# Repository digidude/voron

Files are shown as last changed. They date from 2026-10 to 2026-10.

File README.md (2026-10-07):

# Voron 2.4 — Klipper config + notes

Klipper config, calibration prints, and working notes for a Voron 2.4 (250 mm, BTT Octopus, Beacon RevH, Stealthburner + Clockwork 2, Klipper / Mainsail / KlipperScreen).

The goal of the overhaul: first layers that stick, and a failed print that retries in about a minute instead of 5–20.

**Status (2026-10-04):** `config_v2` is checked in a Klipper simulator but **not yet installed on the printer**. The first real run must be supervised.

## What's where

| Path | What it is |
|---|---|
| [`printer_data/config_v2/`](printer_data/config_v2/) | **The new config.** Its [README](printer_data/config_v2/README.md) has the install steps, rollback, and every change with the reason |
| [`printer_data/config/`](printer_data/config/) | The original config as copied from the Pi on 2026-10-03, kept for comparison. `proposed/` holds the first Step 2 drafts (superseded by `config_v2`) |
| [`test_prints/`](test_prints/) | Calibration prints in the order to run them |
| [`docs/notes/`](docs/notes/) | Working notes: the Step 1 review, the Step 2 drafts, a config_v2 summary, and the [Pi v1/v2 setup runbook](docs/notes/2026-10-07-pi-v1-v2-setup-runbook.md) |

Live guides (shared docs, printable, export to PDF / Word / Markdown):

- **Voron 2.4 Config Overhaul — Handoff Guide:** install walkthrough, Mainsail setup, experiment order, results log
- **Orca Slicer from Scratch — Voron 2.4:** presets, start G-code, calibration, sharing presets

Ask Dan for the links (they're private docs, shared per person).

## Seeing what changed

The history is built so each commit is one step:

1. Original Pi config
2. Step 2 drafts (`config/proposed/`)
3. `config_v2` clean rebuild
4. Macro cleanup (renames, hidden helpers)
5. VIEW_VARIABLES + KlipperScreen menu
6. Test prints, notes, this README

Ways to read the diffs:

- **On GitHub:** click **Commits**, then any commit for a side-by-side diff (gear icon → *Split*). Steps 4 and 5 are the readable ones.
- **Compare two points:** `https://github.com/<user>/voron/compare/<commit-a>...<commit-b>`
- **Locally:** `git log --oneline`, then `git show <commit>` or `git diff <a> <b> -- printer_data/config_v2/macros/`
- **Old vs new config:** the folder layout changed completely, so a file-by-file diff isn't useful. Compare by topic, e.g. `config/active_config/system/start_stop.cfg` vs `config_v2/macros/print_start_end.cfg`. In VS Code: select both files → right-click → *Compare Selected*.

## Not in this repo (on purpose)

- `deprecated_config/telegram_config.conf`: it contains a Telegram bot token and API key.
- The 19 timestamped `printer-2024*/2025*.cfg` auto-backups and Mainsail theme images.
- Ellis' first-layer patch and EM-cube STLs (no license to redistribute). Download them from [Ellis' Print Tuning Guide](https://github.com/AndrewEllis93/Print-Tuning-Guide). See `test_prints/README.md`.
- Everything else in this folder (Klipper, Moonraker, Mainsail, etc.). Those are installed software copied from the Pi, not config.

## Licenses

Config files are a personal setup, shared as-is. `test_prints/` includes GPL-3.0 files from Klipper and Voron Design; see `test_prints/README.md` for sources.

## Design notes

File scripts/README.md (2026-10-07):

# scripts/ — run these ON THE PI

Switch the printer between the original config (**v1**) and the rebuilt one (**v2**) with one command. Both live as git branches in `~/printer_data/config`.

| Script | When | What it does |
|---|---|---|
| `setup-config-git.sh` | Once | Backs up the config, makes it a git repo, commits today's config as branch `v1`, installs config_v2 as branch `v2`, leaves the printer on **v1** |
| `switch-config.sh v1\|v2` | Any time the printer is idle | Saves SAVE_CONFIG changes on the current branch, switches, restarts Moonraker + FIRMWARE_RESTART + KlipperScreen, reports whether Klipper is ready |
| `switch-config.sh` | Any time | Shows which config is active |
| `_common.sh` | — | Shared helpers (idle check, restarts) |

## First time

From the Mac:
```bash
scp -r ~/dev/voron/printer_data/config_v2 pi@<printer>:~/config_v2
scp -r ~/dev/voron/scripts               pi@<printer>:~/scripts
```
On the Pi (SSH):
```bash
chmod +x ~/scripts/*.sh
~/scripts/setup-config-git.sh      # printer stays on v1
~/scripts/switch-config.sh v2      # try v2
~/scripts/switch-config.sh v1      # go back any time
```

## Safety built in
- Refuses to run while a print is running or paused.
- `setup` refuses if the config folder is already a git repo, and makes a full copy to `~/printer_data/config_backup_<date>` first.
- If the Pi user isn't `pi`, `setup` fixes v2's `mainsail-config` include path.
- Nothing is deleted: v2's branch moves `active_config/` and `deprecated_config/` into `archive/`; v1 still has them in place.

## Things to know
- **SAVE_CONFIG results stay with their branch.** PID, Beacon model or mesh saved on v2 doesn't show up on v1.
- **First-layer Z offset is in different places:** v1 hard-codes `SET_GCODE_OFFSET Z=0.04` in `active_config/system/start_stop.cfg`; v2 uses `variable_z_hot_offset` in `macros/print_start_end.cfg`.
- **Mainsail macro groups** are stored in Mainsail, not the config. Groups made for v2 names show missing buttons on v1.
- **Orca needs no change.** Both accept `PRINT_START HOTEND=… BED=…`.
- Compare the two: `cd ~/printer_data/config && git diff v1 v2`

## Tested
In a simulated Pi home folder (Moonraker/systemctl stubbed): setup, v1→v2→v1, auto-save of a SAVE_CONFIG change, refusal while printing, unknown branch, re-running setup, non-`pi` username. After setup and after switching back, v1 is byte-identical to the original config; v2 is identical to `config_v2/`. Not yet run on the real Pi.

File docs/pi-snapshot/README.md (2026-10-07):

# Pi snapshot (2026-10-07)

Read-only capture of the printer Pi from `scripts/backup-pi.sh`. Non-secret half only; the config tarball and Moonraker DB export stay local in `backups/` (gitignored).

Note: `klipper.config` is a stale menuconfig (atmega32u4), not the Octopus build.

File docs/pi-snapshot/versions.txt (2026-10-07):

# name  commit  branch  origin
klipper 461c4e3722c3a897fba1c6b3f0780a5315043842 master https://github.com/Klipper3d/klipper.git
moonraker 9e676eba6b02661a4dfa3ec6e7ac3f3504498e6d master https://github.com/Arksine/moonraker.git
mainsail-config ff3869a621db17ce3ef660adbbd3fa321995ac42 master https://github.com/mainsail-crew/mainsail-config.git
KlipperScreen f2eb6919c0fcbcd4bab91ba59a5708415963d2ac master https://github.com/jordanruthe/KlipperScreen.git
crowsnest cf936dabdcf6a3d1eb0138d8eea9044745b40db6 master https://github.com/mainsail-crew/crowsnest.git
sonar 74494cc37e415e7c43e9e497d53fbabc252a5b40 main https://github.com/mainsail-crew/sonar.git
beacon_klipper 3eb0134607664734ccf5cd94cb51840e1c8b27b3 master https://github.com/beacon3d/beacon_klipper.git
mainsail v2.19.0

# Klipper extras that are symlinks or non-stock (e.g. beacon.py)
/home/pi/klipper-led_effect/src/led_effect.py
/home/pi/beacon_klipper/beacon.py

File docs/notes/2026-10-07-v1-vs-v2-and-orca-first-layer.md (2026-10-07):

# Orca first-layer setup + config v1 → v2 differences (2026-10-07)

"v1" = what's on the Pi today (`printer_data/config/` → `active_config/…`).
"v2" = the rebuild in `printer_data/config_v2/` (not installed yet).
Differences below were pulled by flattening both configs (following every `[include]`) and comparing section by section, then reading the macros.

---

## Part A — Orca: first-layer test with PLA

### Why PLA first
- Sticks to PEI at a low bed temp (60 °C), needs no enclosure heat soak, no warping.
- PETG can bond *too* well to smooth PEI and tear the surface. ASA/ABS need a 10+ min soak and a warm chamber — the hardest case. Get the machine right with PLA, then move back to ASA.
- For PLA: **front doors open or top panel off** (a hot chamber softens PLA in the heatbreak and clogs).
- Clean the PEI sheet with dish soap + hot water first, then don't touch the print area.

### Turning on Advanced in Orca 2.4.2
- It's still there, but it's **per panel**: a small **Advanced** switch in the header of the Process settings in the left sidebar (next to the process preset name). The Printer and Filament settings windows each have their own switch.
- If you can't find it: **OrcaSlicer → Preferences → Developer mode** shows every setting everywhere (same effect, permanent).

### Plate layout (`Klipper Square - 01 first layer.3mf`)
Right now the plate has `Klipper_square.stl` (a multi-layer 60 mm square) + one 0.2 mm patch.
1. Delete `Klipper_square` from the plate (it's not a first-layer test and adds time).
2. Keep `First_Layer_Patch-0.2mm` (matches your 0.2 mm first layer). Right-click → **Clone** → 4 more copies.
3. Place them (Object list → Position X/Y), patch centres at:
   - (40, 40) · (210, 40) · (40, 210) · (210, 210) · (125, 125)
   - These stay inside the mesh area (25–225) and clear of the purge line at X=1.
4. Don't use Arrange (A) — it clusters them in the middle.

### Settings to change

| Where | Setting | Now | Change to | Why |
|---|---|---|---|---|
| Plate dropdown (top of plate) | Plate type | High Temp Plate | Match your sheet (Textured PEI or High Temp/smooth PEI) | Orca picks bed temp by plate type |
| Filament: Generic PLA @System | Bed temp, first layer + other layers | 55 °C | **60 °C** | Standard PLA-on-PEI temp |
| Filament | Nozzle temp | 220 / 220 | keep | Fine for generic PLA |
| Process → Speed → Initial layer | First layer speed | 50 mm/s | **30 mm/s** | Slow while diagnosing |
| Process → Speed → Initial layer | First layer infill speed | 105 mm/s | **40 mm/s** | 105 is fast enough to drag lines off |
| Process → Others → Bed adhesion | Brim type | Auto | **No-brim** (for this test only) | A brim on a 1-layer patch hides what you're judging |
| Printer → Motion ability | Emit limits to G-code | On (max accel 20000, speed 300, jerk 12) | **Off** — or set to match printer.cfg (accel 4000, speed 300) | When on, Orca sends `SET_VELOCITY_LIMIT` that overrides printer.cfg's 4000 accel cap |
| Process → Speed → Acceleration | Enable accel_to_decel | On | **Off** | Klipper deprecated ACCEL_TO_DECEL (replaced by minimum_cruise_ratio) |

Leave alone (already right): first layer height 0.2, first-layer line width 0.5, first-layer accel 500, fan off for layer 1, flow ratio 0.98, Orca pressure advance off (Klipper's 0.04 applies), relative E, label objects on, start G-code `PRINT_START HOTEND=… BED=…` (works with both v1 and v2).

### Running it
1. Slice, send, start. Watch the first patch go down.
2. Babystep Z in Mainsail (±0.01–0.02) until lines just merge — no gaps, no ridges.
3. Note the total babystep. On v2 it's added to `variable_z_hot_offset` (now 0.04); on v1 it goes in the hard-coded `SET_GCODE_OFFSET Z=0.04` near the end of `PRINT_START` in `active_config/system/start_stop.cfg`.
4. Corners vs. centre tell you whether it's Z offset (all the same) or mesh/QGL (corners differ).

**Heads-up:** until v2 is installed, every attempt runs v1's full PRINT_START (4 homes + full 81-point mesh, no retry shortcut). That's the 5–20 min. See Part C to get v2 on with an easy way back.

---

## Part B — v1 vs v2, step by step

### 1. PRINT_START sequence (the big one)

| # | v1 (today) | v2 |
|---|---|---|
| 0 | Clear mesh, zero offset | Same + relative extrusion (M83), cancel keep-hot timer, set exhaust policy |
| 1 | **Home first** (G28), bed not heating yet | **Start bed + nozzle (150 °C) heating, then home** while they heat |
| 2 | Nozzle 150, **wait for bed** | Park over bed centre, wait for bed |
| 3 | No soak | **Soak 10 min only if bed ≥ 90 °C** (ASA/ABS). PLA: none. Chamber-temp wait if a chamber thermistor is added |
| 4 | `G32`: G28 → QGL → **full G28 again** | Beacon `CALIBRATE=1` on the **hot** bed → QGL (Beacon's recommended order) |
| 5 | Wipe ×1 → contact Z with **CALIBRATE=1** | Wipe ×2 → contact Z (CALIBRATE=0) — the Z zero that's actually used |
| 6 | **Full bed mesh, 9×9 = 81 pts** (`ADAPTIVE=0`) | **Adaptive mesh** (only where parts are), 15×15 density, Beacon scan |
| 7 | Wipe ×3 → **another contact Z** | — (not needed: Z already set after the wipe) |
| 8 | Move over bucket, wait for print temp | Move over bucket, wait for print temp |
| 9 | Wipe ×2, `SET_GCODE_OFFSET Z=0.04` (hard-coded) | `SET_GCODE_OFFSET Z={z_hot_offset}` (one tunable, 0.04) |
| 10 | `_purge_clean` + `_PURGE_LINE` (absolute-E purge, 15 mm retracts, 11 s pauses) | `NOZZLE_PRIME` → `NOZZLE_CLEAN` → `NOZZLE_PURGE_LINE` (relative-E, 0.5 mm retracts, 1 s pauses) |
| — | Every attempt does all of the above | **Retry mode:** if still homed + QGL'd + bed within 15 °C → skips homing, soak, calibrate and QGL. `FULL=1` forces the full run |
| — | No timing | `PS: <step> @ Ns` lines in the console show where time goes |

Net: v1 = 4 homing passes + 81-point mesh every time. v2 = 1 home + 1 hot calibrate + 1 contact Z first time; retries go straight to wipe → Z → mesh → heat → purge.

### 2. Cancel, end of print, idle

| | v1 | v2 |
|---|---|---|
| Cancel | Mainsail default (turns heaters off) | Parks over bucket, 1 mm retract, **keeps bed hot + nozzle 150 °C for 15 min** (works from Mainsail, KlipperScreen, Orca) |
| PRINT_END | 10 mm retract, park at **fixed Z50** (crashes into parts taller than 50 mm), brush wipe | 2 mm retract, park **≥10 mm above the part**, no wipe at bed level |
| Motors after print | stay on until idle_timeout (but v1's PRINT_START re-homes anyway) | stay on until idle_timeout — and PRINT_START **uses** that to skip homing/QGL |
| idle_timeout | 7200 s (2 h) | 1800 s (30 min) |

### 3. Safety fixes

| Setting | v1 | v2 |
|---|---|---|
| extruder `min_temp` | -200 | 0 (instant unplugged/broken-thermistor detection back on) |
| extruder `min_extrude_temp` | 0 | 170 (cold-extrusion protection back on) |
| heater_bed `min_temp` | -250 | 0 |
| `[verify_heater]` extruder/bed | Klipper defaults (always on, just not written in the file) | same defaults, written out so they're visible |
| extruder `max_extrude_only_distance` | default (50) | 120 (lets load/unload macros work) |

### 4. Fans

| Fan | v1 | v2 |
|---|---|---|
| Exhaust | `heater_fan`: 100% whenever bed ≥ 60 °C — pulls heat out of the chamber during ASA | `fan_generic` + `_EXHAUST` macro: **off for ASA/ABS**, 60% for PLA/PETG, 100% for 5 min after a print |
| Controller (electronics) | on only when **bed** ≥ 45 °C | `[controller_fan]`: on whenever **motors or heaters** are on, 60 s tail |

### 5. Probe, QGL, mesh

| Setting | v1 | v2 |
|---|---|---|
| QGL speed | 400 (silently capped at 300) | 300 |
| Mesh points | 9×9, always full bed | 15×15, adaptive |
| Beacon `contact_max_hotend_temperature` | default | 180 (explicit) |
| Beacon `home_z_hop_speed` | default | 30 |
| G32 | G28 → QGL → **G28 (all axes)** | G28 → QGL → **G28 Z only** |

### 6. Macros

- **Renamed** (hidden helpers get `_`, buttons get prefixes): `status_*` → `_status_*`; `case_lights_*` → `LIGHTS_CASE_*`; `CLEAN_NOZZLE`/`dynamic_clean`/`BUCKET_PURGE`/`_PURGE_LINE`/`_PURGE_CLEAN` etc. (7 macros) → `NOZZLE_CLEAN`, `NOZZLE_PRIME`, `NOZZLE_PURGE_LINE`; `DUMP_VARIABLES`/`GET_VARIABLE` → `_DUMP_…`/`_GET_…`.
- **Removed:** `PRINT_START_temp`, `_CG32`, `_CQGL`, `fast_motion_demo` (disabled), `dads_sandbox` (was never included).
- **New:** `PREHEAT`, `COOLDOWN`, `KEEP_HOT`, `PARK_FRONT`, `LOAD_FILAMENT`, `UNLOAD_FILAMENT`, `M600`, `CAL_PID_EXTRUDER`, `CAL_PID_BED`, `CAL_INPUT_SHAPER`, `CAL_BEACON_HOT`, `CAL_FIRST_LAYER`, `VIEW_VARIABLES`.
- Visible macro buttons: 45 → 29.

### 7. Everything else

| Area | v1 | v2 |
|---|---|---|
| Mainsail macros | local copy `active_config/mainsail.cfg` (never updates) | `[include /home/pi/mainsail-config/mainsail.cfg]` (updates with Mainsail) — check the Pi username |
| New sections | — | `[gcode_arcs]`, `[save_variables]` (needs empty `variables.cfg`), `[resonance_tester]` on Beacon's accelerometer, MCU + Pi temperature readouts |
| moonraker.conf | `enable_object_processing: False` | `True` (Orca's exclude-object works without slicer help); Telegram + LED-effect updaters removed |
| KlipperScreen.conf | settings only | + View Variables menus (old settings kept) |
| File layout | `active_config/system/…`, `user/…`, `community/…` | `hardware/…`, `macros/…`, `experimental/…` |

### 8. Identical in both
`[printer]` limits (300 mm/s, 4000 accel), all pins, motor currents, endstops, Z gearing, extruder rotation_distance 22.1 + PA 0.04, input shaper (ei 65.2 / mzv 41.8), Beacon serial + Y offset, mesh area 25–225, and the whole SAVE_CONFIG block (PIDs, Beacon model, saved mesh).

---

## Part C — Switching between v1 and v2

**Recommendation: git branches in `~/printer_data/config` on the Pi.** One command flips every file (printer.cfg, includes, moonraker.conf, KlipperScreen.conf) at once, and `git diff v1 v2` is the same diff your son already reviews.

### Scripts (in this repo: `scripts/`)
- `setup-config-git.sh` — one time. Backs up, creates branch `v1` (today's config, untouched) and `v2` (config_v2 installed per its README steps 2–5), leaves the printer on v1.
- `switch-config.sh v1|v2` — refuses mid-print, commits any SAVE_CONFIG changes on the current branch, switches, restarts Moonraker + FIRMWARE_RESTART + KlipperScreen, reports whether Klipper is ready.
- Full instructions and test notes: `scripts/README.md`.

### Gotchas
- **SAVE_CONFIG is per branch.** A new PID, Beacon model or mesh saved on v2 stays on v2. If you want it on v1 too, copy the `#*#` block across (or `git checkout v2 -- printer.cfg` and edit).
- **Z offset is in different places:** v1 hard-codes 0.04 in PRINT_START; v2 uses `variable_z_hot_offset`. Tune each separately if you go back and forth.
- **Mainsail macro groups** live in Mainsail's database, not the config. Groups set up for v2 names will show missing buttons on v1. Cosmetic.
- **Orca needs no change** — both versions accept `PRINT_START HOTEND=… BED=…`.
- Later, if you want a button for it: Klipper's `gcode_shell_command` extension can run the script from Mainsail. Not worth it until you're switching often.

**Simpler alternative (no git):** keep two folders, `config_v1/` and `config_v2/`, and swap with `mv` + restart. Works, but it's easy to lose a SAVE_CONFIG change and harder to see what differs.

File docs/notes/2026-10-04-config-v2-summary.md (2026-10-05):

# config_v2 — full replacement config (2026-10-03 / 2026-10-04)

Location: `printer_data/config_v2/` (README.md inside has install, rollback, full change list). Supersedes the earlier drafts in `printer_data/config/proposed/`.

Validation: loaded and run in Klipper batch mode at the Pi's exact Klipper version (v0.13.0-419-g2e5802370) with an STM32F446 dictionary; no config errors or deprecation warnings; all macros executed (print, cancel, retry, PRINT_END, G32, M600/RESUME, utilities). [beacon] was stubbed with [probe] for the simulation; Beacon option names verified against the installed beacon.py (v2.0.0-23). Real heating/probing/timing untested. Note: `klipper/out/klipper.dict` on the Mac is a stale AVR build; build a fresh STM32F446 dict for simulation.

Key decisions:
- Baseline: official Voron 2.4 Octopus layout + Beacon contact docs; not Klippain (last release v4.4.0-beta.1, June 2024).
- Mainsail macros included from /home/pi/mainsail-config/mainsail.cfg (verify Pi username).
- Exhaust fan -> fan_generic + _EXHAUST policy; controller fan -> [controller_fan].
- PRINT_START: retry-aware, hot-bed Beacon CALIBRATE=1 before QGL, contact Z after wipe, adaptive 15x15 mesh, z_hot_offset 0.04 (Beacon suggests ~0.06 start).
- Cancel keeps bed/150C nozzle for 15 min; motors stay on after PRINT_END; idle_timeout 1800. Keep-hot is automatic on Mainsail/KlipperScreen/Orca cancel (via _CLIENT_VARIABLE user_cancel_macro); retry = reprint within 15 min.
- Safety limits fixed (min_temp 0, min_extrude_temp 170).
- resonance_tester uses Beacon accelerometer; RP2040 ADXL kept as disabled file.

## Macro cleanup (2026-10-04)
- Convention: UPPER_CASE = user button; `_` prefix = hidden helper/console tool; prefixes CAL_, LIGHTS_, NOZZLE_, PARK_.
- Hidden: `_status_*` (11), `_set_logo_leds_off`, `_set_nozzle_leds_on/off`, `_DUMP_VARIABLES`, `_GET_VARIABLE`.
- Renamed: LIGHTS_CASE_WHITE/OFF/NIGHT; CAL_PID_EXTRUDER, CAL_PID_BED, CAL_INPUT_SHAPER (was SHAPER_CALIBRATE_ALL), CAL_BEACON_HOT, CAL_FIRST_LAYER; NOZZLE_CLEAN, NOZZLE_PRIME (was BUCKET_PRIME), NOZZLE_PURGE_LINE.
- Kept standard names: PRINT_START/END, G32, M600, LOAD_/UNLOAD_FILAMENT (Mainsail/KlipperScreen buttons), PAUSE/RESUME/CANCEL_PRINT.
- experimental/demo_motion_macros.cfg -> .cfg.disabled (empty experimental glob is OK in Klipper).
- Visible macros 45 -> 28 (29 with VIEW_VARIABLES). Re-simulated: all renamed macros run; old names return Unknown command.
- Mainsail macro groups (Print / Prep / Toolhead / Calibration / Lights / Learn) are a manual UI step — layout in config_v2/README.md.

## View Variables (2026-10-04)
- `VIEW_VARIABLES` (macros/debug.cfg): SHOW=tunables (default; list in `_VIEW_TUNABLES.variable_macros`), SHOW=state (homed/QGL/mesh/temps/offset + predicts RETRY vs FULL PRINT_START with reason), NAME= (-> _DUMP_VARIABLES), PATH= (-> _GET_VARIABLE). Read-only.
- New `config_v2/KlipperScreen.conf`: "View Variables" submenu in both __main and __print (My Settings / Printer State / Open Console); auto-generated block from the old file preserved. Verified with KlipperScreen's own config loader.
- Simulated in Klipper: all modes, cold / after PRINT_START / after cancel / after COOLDOWN.

Open items: chamber thermistor, BeaconPrinterTools thermal expansion calibration, Orca flow ratio (0.926) + brim, first supervised test on the Pi, Pi undervoltage/throttling warnings (power supply).

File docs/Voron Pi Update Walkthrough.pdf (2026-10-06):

# Voron Pi UpdateWalkthrough

Oct 4, 2026 · @Daniel Klaussen

## Whatthis is and why

The Voron's Raspberry Pi needs four updates, done in a fixed order: package sources, operating system, printer software, then the main board's firmware. Nothing here changes the printer's settings ( printer.cfg and friends stay as they are).
Why now:
The Pi's operating system is out of support. It runs Debian 11 "Bullseye", which reached end of life on August 31, 2026. Debian moved its packages to an archive server, so apt upgrade now fails with hundreds of 404 errors.
The main board's firmware is about three years old. The BTT Octopus runs Klipper v0.11.0 firmware, while the Pi now runs Klipper v0.13. Mainsail shows a warning: MCU 'mcu' has deprecated code… Recompiling and flashing is recommended. It still prints, but the gap will eventually become a hard error.
What it touches: the Pi's package list, the Klipper/Moonraker/Mainsail software, and the Octopus firmware. The Beacon probe updates its own firmware and needs nothing by hand.
What it does not do: reinstall the operating system. That's a separate, later job (see the last section).
Risk: low. The config gets backed up first, and the firmware flash goes through the Octopus's built-in bootloader, which the flash never overwrites. A wrong setting means the board won't connect until it's reflashed correctly. It does not brick the board.

## The order, and why it matters

Each step depends on the one before it. Don't skip ahead.
1. Back up the config. Insurance for everything that follows.
2. Fix the package sources. apt can't download anything until it points at Debian's archive server.
3. Upgrade the OS packages, then reboot. Klipper and Moonraker run on top of these libraries (Python, systemd, OpenSSL), so the foundation goes first.

Voron Pi Update Walkthrough

4. Update the printer software in Mainsail's update manager. Order: Moonraker, then Klipper and Beacon together, then everything else. Klipper and the Beacon plugin must end up on matching versions, because the plugin hooks into Klipper's Z homing code, which changed in May 2026.
5. Reflash the Octopus firmware. It has to be built from the Klipper version installed in
step 4. Flash it any earlier and it will be out of date again as soon as Klipper updates.
6. Verify. Restart, check versions, home, level, and read the logs.
If update manager was already run before steps 2 and 3, that's fine. Do steps 2 and 3, then open update manager again and confirm everything shows as up to date before moving to
step 5.

## Before you start

You'll need:
A computer that can SSH into the Pi (user pi ). Replace <printer-ip> below with the Pi's address.
A microSD card, 32 GB or smaller, formatted FAT32, and a way to write to it.
Physical access to the printer. The Octopus's SD slot is inside the electronics bay.
No print running.
Back up the config (step 1). On the Pi:

cd ~
tar czf printer_data-backup-$(date +%F).tgz printer_data/config

Then copy it off the Pi, from your own computer:

scp pi@<printer-ip>:~/printer_data-backup-*.tgz ~/Desktop/

Note the current Klipper version in case you need to roll back:

git -C ~/klipper log -1 --format='%h %cs'

Write it here: ______________________

## Step 2: Point apt at Debian's archive

Save a copy of the current sources file, then look at what's there:

sudo cp /etc/apt/sources.list /etc/apt/sources.list.bak
cat /etc/apt/sources.list
ls /etc/apt/sources.list.d/

Edit the file with sudo nano /etc/apt/sources.list . Replace every Debian line
( deb.debian.org or security.debian.org ) with these two:

deb http://archive.debian.org/debian bullseye main contrib non-free
deb http://archive.debian.org/debian-security bullseye-security main contrib non-free

Delete any bullseye-updates or bullseye-backports line, or put # in front of it. Leave raspi.list in /etc/apt/sources.list.d/ alone. That's the Raspberry Pi repo, and it still works.
Save with Ctrl+O, Enter, then exit with Ctrl+X. Then:

sudo apt update

Expected: no 404 errors. If it says a Release file "is not valid yet" or "has expired", run this instead:

sudo apt -o Acquire::Check-Valid-Until=false update

## Step 3: Upgrade the OS packages and reboot

sudo apt upgrade

Answer Y to continue.
If it asks whether to keep or replace a config file (nginx, sshd), choose keep your currently-installed version. That's the default, so just press Enter.
About 125 packages should install, the same list that failed before (systemd, OpenSSL, Python 3.9, nginx and so on).
When it finishes:

sudo reboot

Wait for the Pi to come back, then confirm Mainsail loads in the browser before going on.

## Step 4: Update the printer software

4a. Check the Klipper folder for local edits first. Klipper's version currently ends in -dirty , which means files in ~/klipper were edited. Update manager may refuse to update a dirty repo.

git -C ~/klipper status --short
git -C ~/klipper diff --stat

Nothing listed: go to 4b.
Files listed, but diff --stat shows 0 insertions, 0 deletions : only file permissions changed. Fix it with git -C ~/klipper config core.fileMode false and check again.
Real line changes: stop. Don't use "Hard Recovery" in Mainsail, because that wipes the changes. Save the git diff output and decide whether those edits matter before continuing.
4b. Run update manager in this order. In Mainsail, go to Machine → Update Manager and click Refresh. Then:
1. System (OS packages). Should now show nothing to do after step 3.
2. moonraker
3. klipper, then beacon right after it. Never leave one updated and the other behind.
4. Everything else: mainsail, mainsail-config, KlipperScreen, crowsnest, led_effect, sonar, moonraker-telegram-bot.
Expected: every row shows as up to date, none as dirty or invalid.
Note: Moonraker 0.11 now rejects a wrong API key instead of falling back to trusted-network access. If the Telegram bot stops responding afterwards, that's the likely cause. It's a nice-to-have, not needed to print.

## Step 5: Reflash the Octopus firmware

The Octopus (STM32F446) talks to the Pi over the Pi's GPIO serial pins ( /dev/ttyAMA0 ), not USB. So the firmware goes on by SD card.
5a. Build the firmware on the Pi:

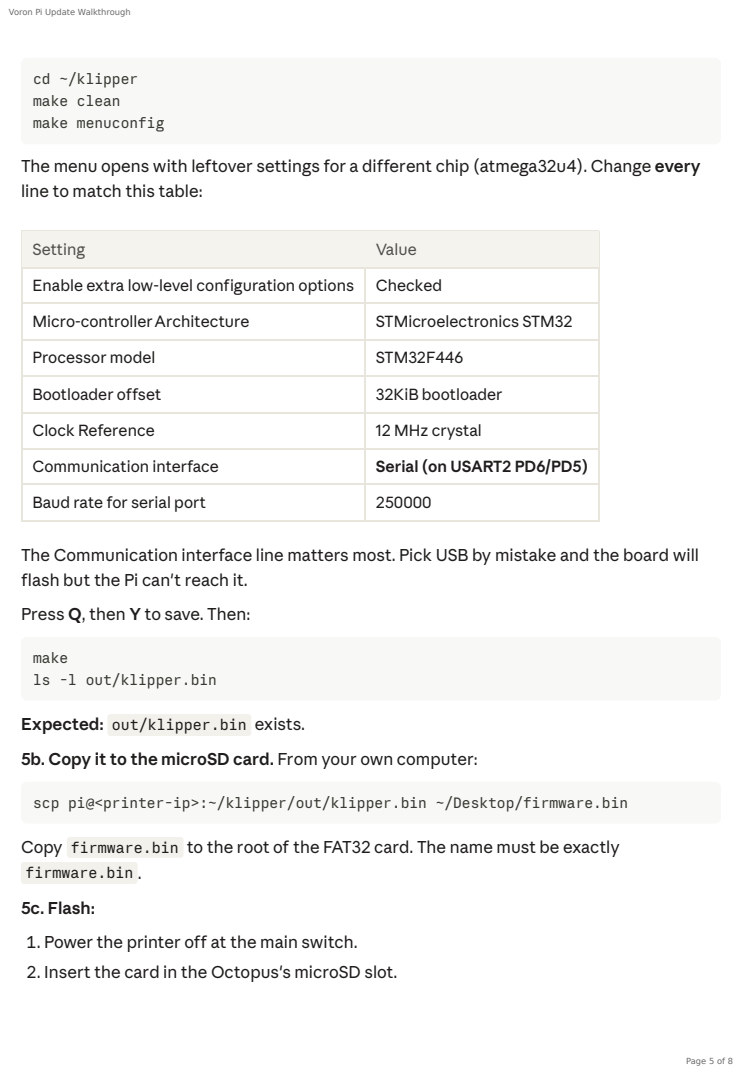
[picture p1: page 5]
cd ~/klipper make clean make menuconfig

The menu opens with leftover settings for a different chip (atmega32u4). Change every
line to match this table:

Setting | Value
Enable extra low-level configuration options | Checked
Micro-controllerArchitecture | STMicroelectronics STM32
Processor model | STM32F446
Bootloader offset | 32KiB bootloader
Clock Reference | 12 MHz crystal
Communication interface | Serial (on USART2 PD6/PD5)
Baud rate for serial port | 250000

The Communication interface line matters most. Pick USB by mistake and the board will
flash but the Pi can't reach it.
Press Q, then Y to save. Then:

make
ls -l out/klipper.bin

Expected: out/klipper.bin exists.
5b. Copy it to the microSD card. From your own computer:

scp pi@<printer-ip>:~/klipper/out/klipper.bin ~/Desktop/firmware.bin

Copy firmware.bin to the root of the FAT32 card. The name must be exactly
firmware.bin .
5c. Flash:
1. Power the printer off at the main switch.
2. Insert the card in the Octopus's microSD slot.

3. Power on and wait about 30 seconds.
4. Power off and remove the card.
5. Check the card on your computer. If the file is now named FIRMWARE.CUR , the flash worked.
6. Power the printer back on.
The Beacon probe updates its own firmware when Klipper starts, so there's nothing to do for it. If the ADXL accelerometer (rp2040) is plugged in and Mainsail shows a version warning for it too, it needs its own build. It isn't needed for printing, so leave it unplugged for now.

## Step 6: Verify

In Mainsail, with the printer powered on:

grep -iE "deprecat|error|mismatch" ~/printer_data/logs/klippy.log | tail -30
grep -iE "deprecat|error|warning" ~/printer_data/logs/moonraker.log | tail
-30

Some old error lines from before the update are normal. Look at the newest ones, at the bottom.

No MCU warning. The deprecated code message is gone.
Versions match. Under Machine → System Loads, mcu shows a v0.13.0 version that matches the Klipper host version, and beacon shows its version.
Home all ( G28 ). All three axes home normally. Watch the first Z home closely, with a hand near the power switch.
Quad gantry level ( QUAD_GANTRY_LEVEL ). Completes without errors.
Heaters. Set the bed to 60 °C and the nozzle to 150 °C. Both reach temperature and hold it.
Logs are clean. On the Pi:

## If something goes wrong

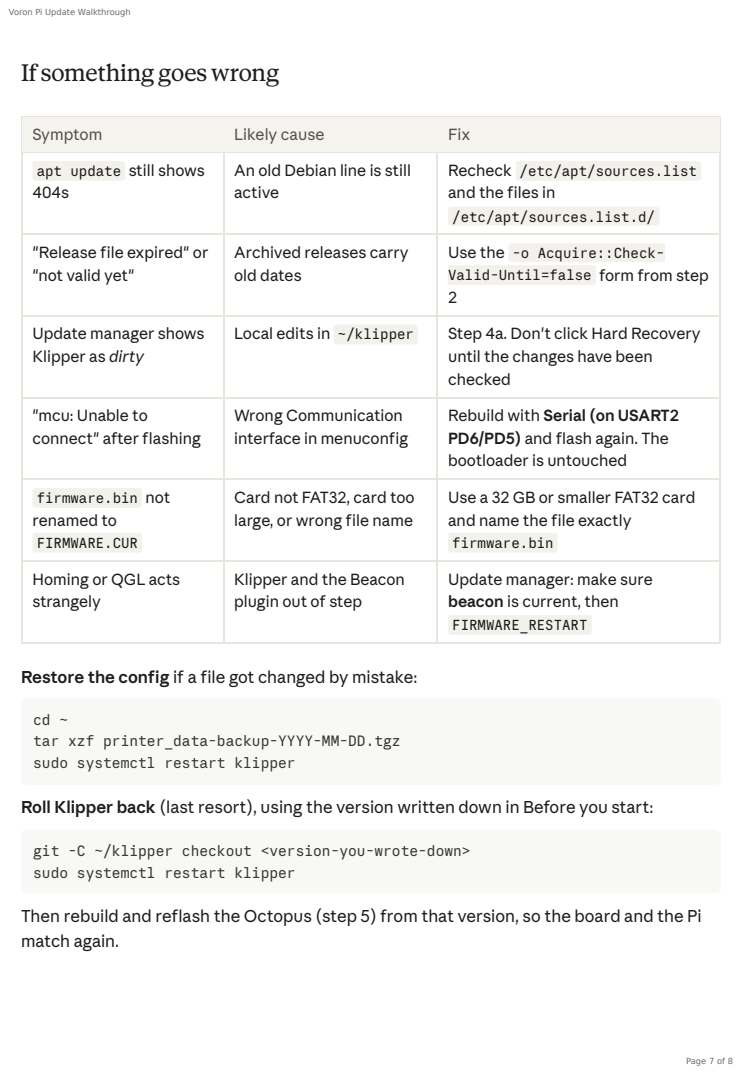
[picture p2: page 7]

Symptom | Likely cause | Fix
apt update still shows 404s | An old Debian line is still active | Recheck /etc/apt/sources.list and the files in /etc/apt/sources.list.d/

"Release file expired" or "not valid yet" | Archived releases carry old dates | Use the -o Acquire::Check-Valid-Until=false form from step 2

Update manager shows Klipper as dirty | Local edits in ~/klipper | Step 4a. Don't click Hard Recovery until the changes have been checked

"mcu: Unable to connect" after flashing | Wrong Communication interface in menuconfig | Rebuild with Serial (on USART2 PD6/PD5) and flash again. The bootloader is untouched

firmware.bin not renamed to FIRMWARE.CUR | Card not FAT32, card too large, or wrong file name | Use a 32 GB or smaller FAT32 card and name the file exactly firmware.bin

Homing or QGL acts strangely | Klipper and the Beacon plugin out of step | Update manager: make sure beacon is current, then FIRMWARE_RESTART

Restore the config if a file got changed by mistake:

tar xzf printer_data-backup-YYYY-MM-DD.tgz
sudo systemctl restart klipper

Roll Klipper back (last resort), using the version written down in Before you start:

git -C ~/klipper checkout <version-you-wrote-down>

Then rebuild and reflash the Octopus (step 5) from that version, so the board and the Pi
match again.

## Later: a fresh operating system

These steps get apt working again, but Bullseye won't receive any more security fixes. That's acceptable for a printer on a home network. Don't expose Mainsail to the internet (no port forwarding).
The proper fix is to reflash the Pi's SD card with current Raspberry Pi OS Lite (Bookworm or Trixie). Then reinstall Klipper, Moonraker, Mainsail, KlipperScreen and Beacon with KIAUH, and copy printer_data/config back in. Plan it after the first-layer work is settled, so the OS and the printer config don't change at the same time.

## Sign-off

Approved to proceed: ______________________ Date: __________ Done by: ______________________ Date: __________

Step 1: Config backed up and copied off the Pi
Step 2: apt sources point at archive.debian.org; apt update runs clean
Step 3: OS packages upgraded; Pi rebooted
Step 4: Update manager all current (Moonraker → Klipper + Beacon → the rest)
Step 5: Octopus flashed; FIRMWARE.CUR on the card
Step 6: No MCU warning; homing, QGL and heaters OK; logs clean

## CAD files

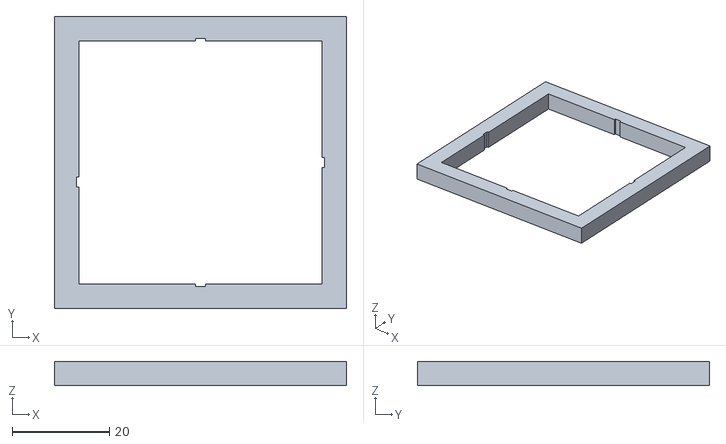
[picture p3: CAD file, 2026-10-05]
test_prints/01_first_layer/Klipper_square.stl
60.0 x 60.0 x 5.00

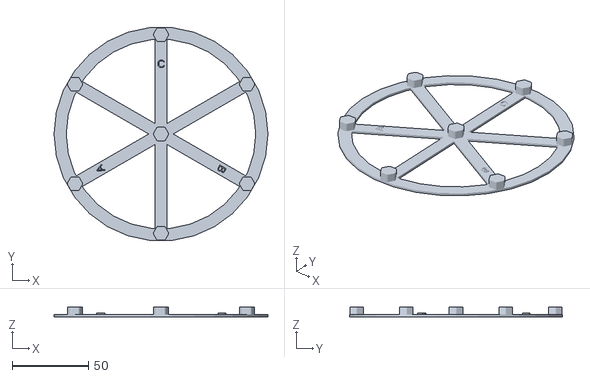
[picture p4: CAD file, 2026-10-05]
test_prints/02_size/calibrate_size.stl
140.0 x 139.2 x 6.50

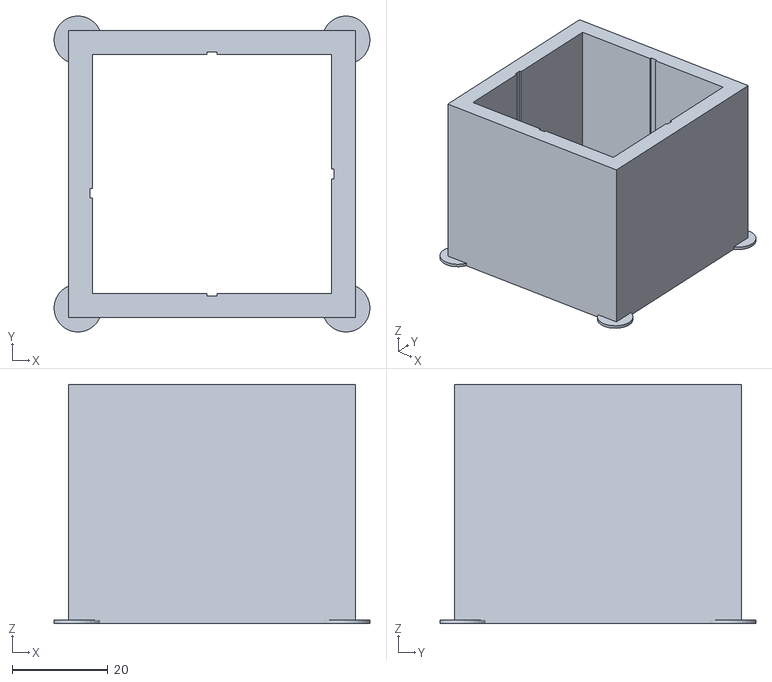
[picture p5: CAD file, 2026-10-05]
test_prints/05_pressure_advance/square_tower.stl
66.0 x 65.9 x 50.0

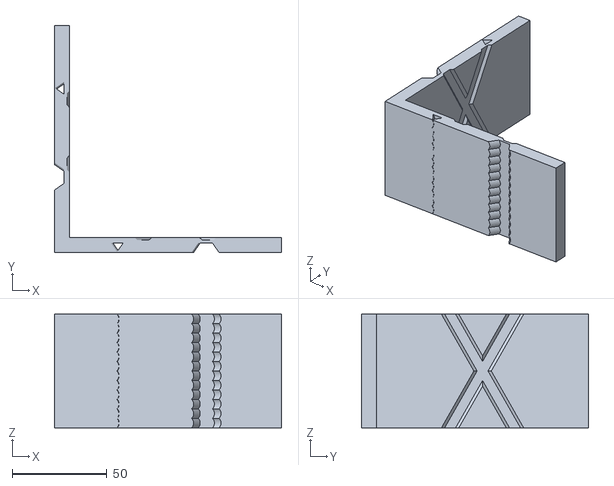
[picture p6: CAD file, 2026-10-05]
test_prints/06_input_shaper_check/ringing_tower.stl
120.0 x 120.0 x 60.0

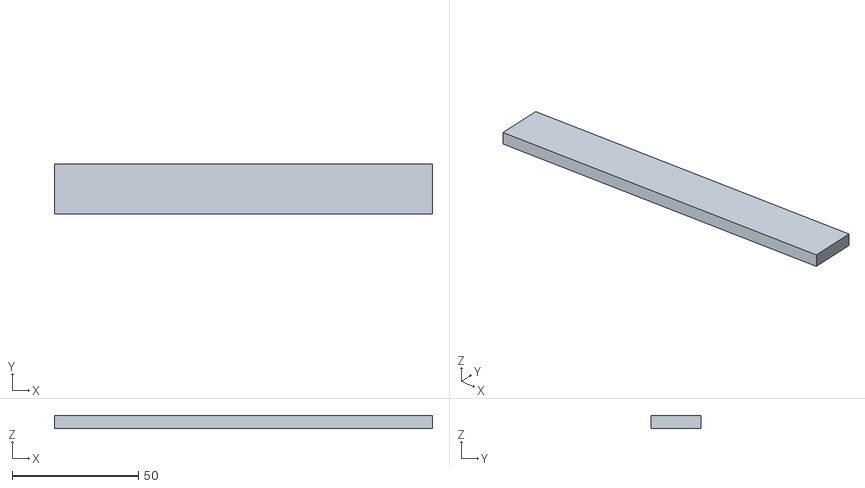
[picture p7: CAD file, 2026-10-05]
test_prints/09_abs_warp_test/Warp_Bar_150x20x5.stl
150.0 x 20.0 x 5.00

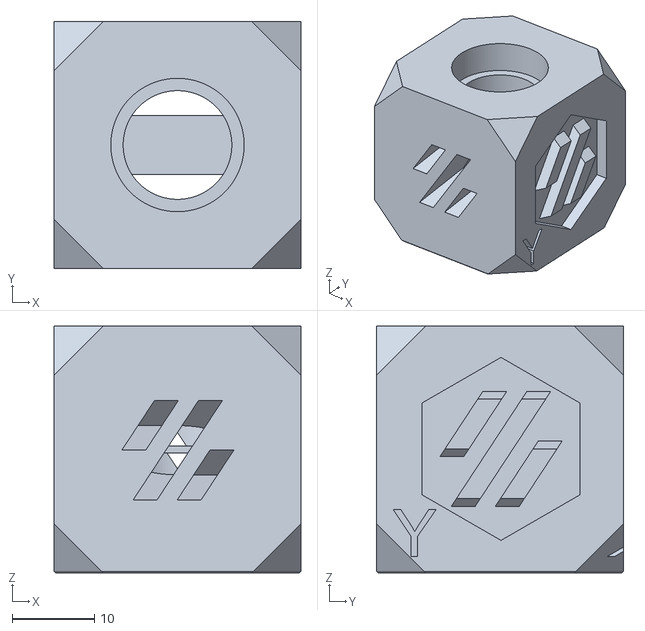
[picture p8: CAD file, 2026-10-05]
test_prints/10_overall_voron_cube/Voron_Design_Cube_v7.stl
30.0 x 30.0 x 30.0

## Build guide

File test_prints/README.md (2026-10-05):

# Voron 2.4 test prints

Run these in folder order: each step assumes the earlier ones are dialed in. Change one thing per print and write down the value (results log in the Handoff Guide).

Steps with no folder (temperature, retraction, max speed, tolerance) are generated inside Orca: **Calibration** menu. No file needed.

| # | Folder / where | File(s) | What it tells you | How to read it |
|---|---|---|---|---|
| 01 | `01_first_layer/` | `First_Layer_Patch-0.2mm.stl` (match your first-layer height; 0.24 / 0.25 / 0.3 also included) | Z offset + mesh, everywhere on the bed | Place 5 copies: 4 corners + center. Babystep live until lines just merge, no gaps or ridges. Add the total to `variable_z_hot_offset` |
| 02 | `02_size/` | `calibrate_size.stl` (Klipper) | X/Y accuracy and skew | Measure with calipers; Klipper's `skew_correction` docs explain the math |
| 03 | Orca → Calibration | Temp tower | Best nozzle temp | Pick the cleanest section |
| 04 | `04_flow_em_cubes/` | `labeled_0.900-1.050/EM_Cube-*.stl` (or the unlabeled one) | Flow ratio (extrusion multiplier) | Ellis' method: print several, pick the smoothest top surface without overfill. Labeled cubes have the value embossed. Your ASA is at 0.926 now; expect 0.95–1.0 |
| 05 | `05_pressure_advance/` | `square_tower.stl` (Klipper) — or Orca's PA pattern | Corner sharpness | Klipper docs: "Pressure advance" tuning. Orca's pattern test is quicker |
| 06 | `06_input_shaper_check/` | `ringing_tower.stl` (Klipper) | Ghosting after `CAL_INPUT_SHAPER` | Ripples next to the notches should be gone |
| 07 | Orca → Calibration | Retraction test | Stringing | Shortest retraction with no strings |
| 08 | Orca → Calibration | Max volumetric speed | Hotend melt limit | Note where the walls start to fail; use ~80% of it |
| 09 | `09_abs_warp_test/` | `Warp_Bar_150x20x5.stl` | ABS/ASA corner lifting | Print along X, 3 walls, 15% infill, no brim first. Lay it on glass: any rocking = warp. Repeat with brim / after chamber thermistor |
| 10 | `10_overall_voron_cube/` | `Voron_Design_Cube_v7.stl` | Overhangs, bridges, text, dimensions | Voron's own all-in-one check. 30 mm cube |
| 11 | Voron GitHub | A real Voron part in ASA (e.g. a spare Stealthburner part) | Final exam | Fits + no warp = done |

**Git note:** Ellis' first-layer patches and EM cubes (`01_first_layer/First_Layer_Patch-*.stl`, everything in `04_flow_em_cubes/`) aren't in the git repo because they have no redistribution license. Download them from his repo (link below) into those folders.

## Sources

- First-layer patches and EM cubes: Ellis' Print Tuning Guide — github.com/AndrewEllis93/Print-Tuning-Guide (`test_prints/`). Guide: ellis3dp.com
- Voron Design Cube v7: github.com/VoronDesign/Voron-2 (`STLs/Test_Prints/`), GPL-3.0 (license in that folder)
- `calibrate_size`, `square_tower`, `ringing_tower`: Klipper (`klipper/docs/prints/`), GPL-3.0
- Warp bar: simple 150 × 20 × 5 mm box generated for this project

Downloaded 2026-10-04.

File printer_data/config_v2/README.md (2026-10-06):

# Voron 2.4 — config_v2

This is a clean rebuild of the Klipper config. The layout follows the official Voron 2.4 / BTT Octopus reference config, and the probing sequence follows Beacon's documentation. All machine-specific values are carried over from your old config. Drafted 2026-10-03.

## Related

- **Handoff Guide** (overview, decisions, and the results log for test prints): https://claude.ai/artifact/BYiP8vtwQ9XhrJBHuGidYb
- **Orca Slicer from Scratch** (slicer setup to pair with this config): https://claude.ai/artifact/4QghdcxjAcYA2dbD4WtgKx
- **Test prints**: `voron/test_prints/README.md` on the Mac copy (`../../test_prints/` from here). 10 calibration steps in order, STLs included. These stay on the Mac; they don't get copied to the Pi.
- **History:** `config/proposed/` held the first Step 2 drafts (PRINT_START, keep-hot, exhaust). All of that is folded into this folder; `proposed/` is kept only for reference. `config/deprecated_config/` and `config/active_config/` are the original files from the Pi; see Install step 2.

## How it was checked

- **Real Klipper, simulated printer.** The config was loaded by the same Klipper version as your Pi (v0.13.0-419) in batch mode, using an STM32F446 build of the firmware. Klipper accepted every section with no errors or deprecation warnings. Every macro ran to completion, including a simulated print, a cancel, a retry, PRINT_END, G32, M600/RESUME and the utility macros.
- **Beacon, by hand instead.** The `[beacon]` section can't be loaded without the physical Beacon attached, so the simulation used a stand-in probe. Every Beacon option name was checked against your installed `beacon.py` instead.
- **Not tested:** real temperatures, real probing and timings. The first real run is still a supervised test.

## File layout

```
printer.cfg                 includes + [mcu] [printer] input shaper, idle timeout, SAVE_CONFIG block
hardware/
  motors.cfg                X/Y/Z steppers + TMC2209 drivers
  extruder.cfg              Clockwork 2 + hotend heater
  bed.cfg                   bed heater
  beacon.cfg                Beacon, QGL, bed mesh, resonance tester
  fans.cfg                  all fans + _EXHAUST policy
  leds.cfg                  case lights + Stealthburner LEDs + hidden _status_ macros
  sensors.cfg               Octopus/Pi temps + chamber thermistor template
macros/
  print_start_end.cfg       PRINT_START (retry-aware) / PRINT_END
  cancel_keep_hot.cfg       cancel = park + keep warm 15 min
  nozzle_clean.cfg          NOZZLE_CLEAN, NOZZLE_PRIME, NOZZLE_PURGE_LINE
  utility.cfg               G32, PARK_*, PREHEAT, COOLDOWN, LOAD/UNLOAD, M600
  calibration.cfg           CAL_PID_*, CAL_INPUT_SHAPER, CAL_BEACON_HOT, CAL_FIRST_LAYER
  debug.cfg                 VIEW_VARIABLES (+ _DUMP_VARIABLES, _GET_VARIABLE)
experimental/               auto-included playground (*.cfg)
moonraker.conf              cleaned up
```

## Install (on the Pi)

1. **Back up the current config.**
   `cp -r ~/printer_data/config ~/printer_data/config_backup_$(date +%F)`
2. **Archive the clutter.** Move the 25 `printer-2024*.cfg` / `printer-2025*.cfg` backups, `active_config/` and `deprecated_config/` into a folder named `archive/`. Klipper ignores any file that nothing includes, so this is only for tidiness.
3. **Copy in the new files.** Copy everything from `config_v2/` into `~/printer_data/config/`: `printer.cfg`, `hardware/`, `macros/`, `experimental/` and `moonraker.conf`. Also copy the new `KlipperScreen.conf` (adds the View Variables menu; your existing settings are preserved at the bottom). Keep your existing `crowsnest.conf` and `sonar.conf`; they're unchanged.
4. **Create the save-variables file.** Klipper won't start without it: `touch ~/printer_data/config/variables.cfg`
5. **Check the Pi username.** The first include in `printer.cfg` assumes it's `pi`: `/home/pi/mainsail-config/mainsail.cfg`. If it isn't, fix that path.
6. **Restart.** Restart Moonraker, then run `FIRMWARE_RESTART` from Mainsail.
7. **First test, supervised.** Home, run `G32`, then a small PLA print (dial in with PLA first). Watch the `PS:` lines in the console.

**Rollback:** copy the backup folder back and run `FIRMWARE_RESTART`.

## What changed, and why

### Fixes

| Where | Change | Why |
|---|---|---|
| extruder.cfg | `min_temp` -200 → 0, `min_extrude_temp` 0 → 170 | Restores thermistor-fault and cold-extrusion protection |
| bed.cfg | `min_temp` -250 → 0 | Same |
| fans.cfg | Exhaust: 100%-when-bed-hot → macro controlled. Off for ABS/ASA, 60% for PLA, 5 minutes at 100% after a print | It was pulling heat out of the chamber, a likely cause of corners lifting |
| fans.cfg | Controller fan follows motors and heaters, not the bed | Drivers and Pi had no airflow on cold-bed jobs |
| nozzle_clean.cfg | Purge rewritten for relative extrusion. Retracts cut from 15 mm to 0.5 mm, pauses from 11 s to 1 s | The old purge started the line under-primed; long retracts at print temperature risk heat creep |
| print_start_end.cfg | PRINT_END parks at least 10 mm above the part | The old fixed Z50 would drive the nozzle *into* parts taller than 50 mm |
| print_start_end.cfg | Defaults for BED/HOTEND | Running PRINT_START by hand without values used 0°C |
| printer.cfg | Mainsail macros included from the `mainsail-config` repo | Your copy wasn't getting updates |
| beacon.cfg | QGL speed 400 → 300 | It was being silently capped at max_velocity |

### Speed (faster attempts and retries)

- **PRINT_START** heats the bed and nozzle while homing. It homes Z with contact once, plus one calibration on the hot bed, instead of 4–6 homes. The mesh is adaptive (only where parts are).
- **Retry mode.** If the printer is still homed, levelled and the bed is within 15°C of target, PRINT_START skips homing, QGL and the soak. Add `FULL=1` to force everything.
- **Keep warm on cancel.** A cancel parks over the bucket, retracts 1 mm, and keeps the bed at print temperature and the nozzle at 150°C for 15 minutes.
- **Motors stay on after PRINT_END,** so the next print can skip homing and QGL. `idle_timeout` turns them off after 30 minutes.
- **Time per step.** `PS: <step> @ Ns` lines show where the time goes.
- **G32** re-homes only Z after QGL.

### Quality

- **Heat soak:** 10 minutes automatically for beds at 90°C and above. A chamber-temperature wait takes over if you add a chamber thermistor.
- **Beacon calibration on the hot bed** before QGL, as Beacon's docs recommend.
- **Nozzle expansion offset:** `z_hot_offset` (default 0.04; Beacon suggests about 0.06 as a start) is a single setting to tune.
- **Mesh:** 15×15 points (scanning, so almost no extra time). `zero_reference_position` matches the Beacon home spot.

### New nice-to-haves (all optional)

- **Printer config:** `[gcode_arcs]` (for Orca arc fitting) and `[save_variables]` (persistent macro values).
- **Temperature readouts:** Octopus MCU and Pi CPU temperatures in Mainsail.
- **Chamber thermistor:** template included. Recommended ~$2 upgrade.
- **Input shaper:** `[resonance_tester]` uses Beacon's built-in accelerometer. Your old RP2040/ADXL board is kept as `experimental/adxl_rp2040.cfg.disabled`.
- **Utility macros:** `PREHEAT`, `COOLDOWN`, `KEEP_HOT`, `PARK_FRONT`, `LOAD_FILAMENT`, `UNLOAD_FILAMENT`, `M600`.
- **Calibration macros:** `CAL_PID_EXTRUDER`, `CAL_PID_BED`, `CAL_INPUT_SHAPER`, `CAL_BEACON_HOT`, `CAL_FIRST_LAYER`.
- **Case lights:** the macros are one-line `SET_LED` calls now.
- **moonraker.conf:**
  - Object processing on.
  - Beacon updater left on `dev` (Beacon's official setting; its last tagged release is from 2024).
  - Removed the unused Telegram and LED-effect updater entries (notes inside if you want them back).

### Removed

- `PRINT_START_temp`, `_CG32`, `_CQGL`, `dads_sandbox` (it was never included anyway).
- Seven duplicate purge/clean macros, now three.
- The `klipperScreen.cfg` include. It only held KlipperScreen's own settings, which live in `KlipperScreen.conf`.

### Carried over unchanged (machine-specific)

- **Wiring and Beacon:** all pins, the Beacon serial number, the Beacon Y offset of 25, and the MCU on `/dev/ttyAMA0`.
- **Motion:** motor currents, endstop positions, axis limits and Z gear ratio.
- **Extruder:** `rotation_distance` 22.1 with 50:10 gearing, and pressure advance 0.04.
- **Tuning results:** input shaper (ei 65.2 / mzv 41.8), and the entire SAVE_CONFIG block (PID values, Beacon model, saved mesh).
- **Peripherals:** brush, bucket and purge positions, fan pins, LED colours.

## Macro cleanup (2026-10-04)

Goal: a tidy Mainsail Macros panel. Backup of the pre-cleanup files: `printer_data/config_v2.bak-2026-10-04-pre-macro-cleanup/`.

**Naming convention** (also documented at the top of the macro includes in `printer.cfg`):

- `UPPER_CASE` = a command you run by hand; shows as a button.
- `_anything` = internal helper or console tool; Mainsail hides it.
- Prefixes so related buttons sort together: `CAL_*`, `LIGHTS_*`, `NOZZLE_*`, `PARK_*`.
- Left alone on purpose because other tools look for these names: `PRINT_START`/`PRINT_END` (Orca), `G32`, `M600`, `LOAD_FILAMENT`/`UNLOAD_FILAMENT` (Mainsail and KlipperScreen load/unload buttons), `PAUSE`/`RESUME`/`CANCEL_PRINT` (Mainsail).

**Renames**

| Old | New | Why |
|---|---|---|
| `status_*` (11 macros) | `_status_*` | Internal LED helpers; hidden |
| `set_logo_leds_off`, `set_nozzle_leds_on/off` | `_set_...` | Internal LED helpers; hidden |
| `DUMP_VARIABLES`, `GET_VARIABLE` | `_DUMP_VARIABLES`, `_GET_VARIABLE` | Console tools; hidden but still autocomplete in the console |
| `CASE_LIGHTS_WHITE/OFF/NIGHT` | `LIGHTS_CASE_WHITE/OFF/NIGHT` | Prefix grouping |
| `PID_EXTRUDER`, `PID_BED` | `CAL_PID_EXTRUDER`, `CAL_PID_BED` | Prefix grouping |
| `SHAPER_CALIBRATE_ALL` | `CAL_INPUT_SHAPER` | Prefix grouping |
| `BEACON_CALIBRATE_HOT` | `CAL_BEACON_HOT` | Prefix grouping |
| `FIRST_LAYER_CHECK` | `CAL_FIRST_LAYER` | Prefix grouping |
| `CLEAN_NOZZLE`, `BUCKET_PRIME`, `PURGE_LINE` | `NOZZLE_CLEAN`, `NOZZLE_PRIME`, `NOZZLE_PURGE_LINE` | Prefix grouping |
| `fast_motion_demo` | (disabled) | `experimental/demo_motion_macros.cfg` renamed to `.cfg.disabled` |

All internal calls were updated. Every visible macro has a `description:`. Re-tested in the Klipper simulator (same Klipper version, STM32F446 dictionary, Beacon stubbed out because it needs its own MCU): G32, PRINT_START (full and retry), PRINT_END, CANCEL_PRINT + keep-hot, every renamed macro, and the debug tools all ran with no unknown-command or template errors. The old names correctly come back as "Unknown command".

**Result:** 28 visible macros (22 of ours + 6 from Mainsail), down from 45 (29 with VIEW_VARIABLES, added later). The groups below show only the ones that make sense for what the printer is doing.

### Mainsail macro groups (do this in the Mainsail UI)

Mainsail stores groups in its own database, not in the Klipper config, so this step is manual. Go to **Settings → Macros**, switch **Management** to **Expert**, then add these groups. In Expert mode, a macro that isn't in any group doesn't appear on the dashboard, which is how `PRINT_START`, `PRINT_END` and `SET_PRINT_STATS_INFO` stay off it (Orca calls those).

| Group | Show when | Macros |
|---|---|---|
| **Print** | printing, paused | PAUSE, RESUME, CANCEL_PRINT, M600, SET_PAUSE_NEXT_LAYER, SET_PAUSE_AT_LAYER |
| **Prep** | standby | PREHEAT, COOLDOWN, G32, KEEP_HOT, LOAD_FILAMENT, UNLOAD_FILAMENT |
| **Toolhead** | standby, paused | PARK_FRONT, PARK_REAR, NOZZLE_CLEAN, NOZZLE_PRIME, NOZZLE_PURGE_LINE |
| **Calibration** | standby (collapsed) | CAL_FIRST_LAYER, CAL_BEACON_HOT, CAL_PID_EXTRUDER, CAL_PID_BED, CAL_INPUT_SHAPER |
| **Lights** | always | LIGHTS_CASE_WHITE, LIGHTS_CASE_NIGHT, LIGHTS_CASE_OFF |
| **Learn** | always | VIEW_VARIABLES |

Tip: color the Print group red (PAUSE and CANCEL should be easy to find) and Calibration a muted color.

**If you use these anywhere else, update them:** KlipperScreen custom menus, Mainsail console history, or Orca G-code that called `CLEAN_NOZZLE`/`PURGE_LINE` directly. Orca's standard start line (`PRINT_START ...`) is unchanged.

## View Variables (2026-10-04)

One read-only button for "what is the printer thinking?" Safe to press mid-print. Output goes to the console. Backup of the files before this change: `printer_data/config_v2.bak-2026-10-04-pre-view-variables/`.

| Command | Shows |
|---|---|
| `VIEW_VARIABLES` or `SHOW=tunables` | Your tunable settings: PRINT_START, keep-hot, brush/bucket positions, exhaust |
| `VIEW_VARIABLES SHOW=state` | Homed, QGL, mesh, position, Z offset, temps, and whether the next PRINT_START takes the RETRY path (with the reason if not) |
| `VIEW_VARIABLES NAME=<text>` | Free search over everything (uses `_DUMP_VARIABLES`) |
| `VIEW_VARIABLES PATH=<a.b>` | One exact value (uses `_GET_VARIABLE`) |

- **Mainsail:** click the arrow on the VIEW_VARIABLES button to fill in SHOW / NAME / PATH. It's in the **Learn** group above.
- **KlipperScreen:** a **View Variables** menu on the main screen and in the in-print menu, with My Settings, Printer State and Open Console buttons. Defined in `KlipperScreen.conf`.
- To add another macro to the tunables list, edit `variable_macros` in `_VIEW_TUNABLES` (`macros/debug.cfg`).

Tested in the Klipper simulator (cold start, after PRINT_START, after a cancel, after COOLDOWN, all four modes). `KlipperScreen.conf` was loaded with KlipperScreen's own config parser: no errors, and the menus appear in both menus.

## Orca changes to pair with this (in the slicer, not here)

- **Filament flow ratio:** ASA is currently 0.926. Run Orca's flow calibration; if you don't, try 0.95–1.0 for first-layer adhesion.
- **Brim** on parts with sharp corners for ASA/ABS.
- **Machine start G-code:** no change needed. Optional: add `SOAK=0` when the printer is already heat-soaked.
- **Accel-to-decel:** if Orca's "Klipper: use accel_to_decel" is on, consider turning it off. Klipper replaced `max_accel_to_decel` with `minimum_cruise_ratio` in 2024.

## Suggested next upgrades (not done here)

1. **Chamber thermistor:** see `hardware/sensors.cfg`.
2. **Thermal expansion calibration:** [BeaconPrinterTools](https://github.com/YanceyA/BeaconPrinterTools) measures your nozzle's expansion and sets `z_hot_offset` automatically for each print temperature.
3. **Re-run tuning:** work through `test_prints/README.md` in order (first layer → size → temp → flow → pressure advance → input shaper check → ABS warp). `CAL_INPUT_SHAPER` comes before step 06. Log results in the Handoff Guide.
4. **Mechanical checks:** belt tension (including matched Z belts), bed mounting (one bolt fixed, the others free to slide), and a clean PEI sheet (dish soap and water).

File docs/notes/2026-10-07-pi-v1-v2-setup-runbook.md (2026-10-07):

# Runbook: set up v1/v2 config branches on the Pi

Date: 2026-10-07. Status: **not yet run on the Pi** (as of this note). Everything marked "changes the Pi" needs the owner's OK first.

Result: `~/printer_data/config` becomes a local git repo with branch `v1` (current config, untouched) and `v2` (`config_v2` installed). `switch-config.sh` flips between them. Setup leaves the printer on v1 and restarts nothing.

## Preflight (read-only, checked 2026-10-07)

| Check | Result |
|---|---|
| `git`, `curl`, `python3` on Pi | present |
| `~/mainsail-config/mainsail.cfg` (v2 includes it) | present |
| Printer state | standby |
| Disk | 44 GB free |
| KlipperScreen service | present |
| `~/config_v2`, `~/scripts` | absent: copy first |
| `sudo` | needs a password, so switching must be from an interactive SSH login |

## Steps

1. **Copy from the Mac** (changes the Pi: adds two new folders):
   ```bash
   scp -r ~/dev/voron/printer_data/config_v2 pi@voron.local:~/config_v2
   scp -r ~/dev/voron/scripts               pi@voron.local:~/scripts
   ```
2. **Log in interactively:**
   ```bash
   ssh pi@voron.local
   chmod +x ~/scripts/*.sh
   ```
3. **Run setup** (changes the Pi: backs up and `git init`s the config; printer stays on v1):
   ```bash
   ~/scripts/setup-config-git.sh
   ```
   Backup goes to `~/printer_data/config_backup_<date>`.
4. **Verify nothing changed on v1:**
   ```bash
   cd ~/printer_data/config
   git branch                # v1 (active), v2
   git status --short        # empty
   git diff --stat v1 v2
   ```
5. **Switch to v2** (printer idle; prompts for sudo password; restarts Moonraker, FIRMWARE_RESTART, KlipperScreen):
   ```bash
   ~/scripts/switch-config.sh v2
   ```
6. **Switch back any time:**
   ```bash
   ~/scripts/switch-config.sh v1
   ~/scripts/switch-config.sh        # show active branch
   ```

## After the first switch to v2, check in Mainsail
- Klipper state is ready; Beacon connected
- Heater, fan and temperature readings look sane
- v2 has no SAVE_CONFIG block: redo PID, Beacon model, and bed mesh on v2. They do not carry over from v1.

## Rollback
`switch-config.sh v1`. Fallback: the `config_backup_<date>` folder from step 3.

## Gotchas
- SAVE_CONFIG results stay on the branch that produced them.
- `variables.cfg` is gitignored and shared by both branches.
- The first real run of the switch scripts: earlier tests used stubs only.
- If Moonraker or Klipper doesn't answer after a switch, open Mainsail for the error, then switch back.

## Related
- `scripts/README.md`: script reference
- `scripts/backup-pi.sh`: read-only backup from the Mac (output in gitignored `backups/`)
- `docs/pi-snapshot/`: non-secret snapshot of the Pi's system state (2026-10-07)
- `2026-10-07-v1-vs-v2-and-orca-first-layer.md`: what differs between v1 and v2

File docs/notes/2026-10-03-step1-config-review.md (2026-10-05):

# Voron 2.4 config review (Step 1) — 2026-10-03

Scope: `printer_data/config/printer.cfg` + everything it includes under `active_config/`, `moonraker.conf`, plus the most recent Orca gcode (`carriage_mount_ASA_29m47s.gcode`, ASA, 250/105, relative E). Recommendations only — nothing modified.

## A. Likely contributors to first-layer peeling (fix first)

1. **Exhaust fan runs 100% whenever bed > 60 °C** (`fans.cfg` `[heater_fan exhaust_fan]`, fan_speed 1.0). For ASA/ABS this dumps chamber heat during the whole print -> cold chamber, warping, corners lifting. Change to a `[fan_generic exhaust_fan]` controlled by macro/slicer (off or low for the first layers), or at minimum `fan_speed: 0.3`.
2. **No chamber heat soak.** PRINT_START waits for bed temp only, then goes straight to leveling. ASA on a 250 needs ~10–20 min soak (or chamber thermistor + `TEMPERATURE_WAIT`). Without it, the first layer goes down on a bed whose edges / frame are still moving.
3. **Purge-sequence filament math leaves the nozzle starved at print start.** Slicer uses relative E (M83), and `_TEMP_BUCKET_PURGE` also forces M83. Net sequence: +20 purge, **-10** retract, then `_PURGE_CLEAN` **-5** more, then `_PURGE_LINE` +11 prime -> still ~4 mm retracted when the line starts, then +15 / +30, then -0.2. 15 mm of retract at 250 °C with dwells (3 s, 3 s, 5 s) risks heat creep and an underfed first few cm. Reduce bucket retract to ~0.5–1 mm, drop the extra `G1 E-5`, and rewrite `_PURGE_LINE` explicitly for relative E.
4. **`SET_GCODE_OFFSET Z=0.04` hard-coded in PRINT_START** lifts the nozzle 0.04 mm on top of Beacon contact homing (done at 150 °C). Probably meant as hot-nozzle expansion compensation, but it's a blind number and reduces squish. Verify with a first-layer test + live babystepping and put the result in a variable; also look at Beacon's own hot-nozzle expansion compensation instead of a manual offset.
5. **Orca filament flow ratio 0.926** on that ASA profile (and initial line width 0.5). Low first-layer flow + the lift above = thin, poorly bonded first layer. Calibrate flow; consider 1.0 on layer 1.

## B. Errors / safety

- `extruder min_temp: -200`, `heater_bed min_temp: -250`, `min_extrude_temp: 0` — removes thermistor-fault and cold-extrusion protection. Use `min_temp: 0` (or 10) and `min_extrude_temp: 170`.
- `params.BED|int` / `params.HOTEND|int` have no defaults — a manual `PRINT_START` without params silently uses 0.
- `_TEMP_BUCKET_PURGE` uses `M83 E` (stray param) and never restores mode — harmless with Orca relative E, broken if any slicer/profile uses absolute E.
- `SAVE_CONFIG` block has `[stepper_z] position_endstop = 0.572` while Z uses the Beacon virtual endstop — stale leftover; confirm Klipper isn't warning about it.
- `controller_fan` is a `heater_fan` tied to the bed (>45 °C) — drivers/Pi get no airflow on cold prints. Use `[controller_fan]` (on when steppers enabled).
- `moonraker.conf`: telegram bot entry still "TODO", uses `/home/pi/...` while others use `~` — remove if not installed (stops update-manager errors). Beacon updater on `channel: dev`; consider `stable`.

## C. Redundancy that costs time (feeds Step 2)

PRINT_START does: G28 (contact + autocalibrate) -> G32 (BED_MESH_CLEAR, **G28**, QGL, **G28**) -> wipe -> `G28 Z CONTACT CALIBRATE=1` -> full 9x9 mesh -> 3 wipes -> `G28 Z CONTACT` -> move to Z40, heat hotend 150->250 -> 2 wipes -> bucket purge (11 s of dwells) -> 3 more wipes -> purge line.
- 4 full/Z homes + 2 contact homes; `CALIBRATE=1` duplicates `home_autocalibrate: unhomed`.
- G32's leading G28 is redundant (already homed); only Z re-home is needed after QGL.
- Hotend heats only after all probing — could preheat to 150 earlier (already done) and overlap more of the final heat.
- Mesh is `ADAPTIVE=0` though comment says adaptive; `exclude_object` and Orca labels are already set up, so `ADAPTIVE=1` works.
- QGL `speed: 400` > `max_velocity: 300` (clamped, cosmetic).
- Bed `max_power: 0.6` is the Voron default for heater sizing — a big part of heat time; leave unless heater/SSR rating allows more.

## D. Housekeeping

- `active_config/mainsail.cfg` is a copy of `~/mainsail-config/mainsail.cfg`; include the repo file (or symlink) so updates apply.
- `_CG32` / `_CQGL` only home; never QGL/mesh conditionally — either finish or delete.
- `CLEAN_NOZZLE`, `CLEAN_NOZZLE_WIPES`, `dynamic_clean` are three near-duplicates; keep one with a WIPES param.
- `PRINT_START_temp` and ~25 timestamped `printer-2024*.cfg` backups clutter the config dir; move to an archive folder.
- `G32`, PRINT_START comments stale ("80%", "adaptive").

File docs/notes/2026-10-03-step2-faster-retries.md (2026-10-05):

# Step 2 — faster retries: draft files (2026-10-03)

All drafts live in `printer_data/config/proposed/`. Nothing in the live config was changed or included. **Superseded by `printer_data/config_v2/`.**

## start_stop_v2.cfg — PRINT_START / PRINT_END
Drop-in replacement for `active_config/system/start_stop.cfg`; same macro names, same Orca start gcode.
- Bed + hotend(150) heat in parallel with initial G28.
- Retry-aware: if still homed + QGL applied + bed within 15 C of target -> skip G28, QGL, soak. `FULL=1` forces everything.
- Soak: auto 10 min when BED >= 90 on first attempt; `SOAK=<min>` overrides.
- One contact Z home at controlled 140-160 C nozzle, after a 2-pass wipe. Adaptive mesh (`MESH=0` to skip).
- Final heat over bucket; 15 mm prime, 0.5 mm retract; relative-E purge line (E14 + E10).
- `z_hot_offset` kept at 0.04 (old behavior) as a variable to tune.
- `_PS_MARK` prints elapsed seconds per phase ("PS: ...").
- PRINT_END: retract 10 -> 2 mm; calls `_EXHAUST MODE=end` if installed.
- Calls `_KEEP_HOT_ARM` and `_EXHAUST` only if those files are installed (independent install).

## cancel_keep_hot.cfg — cancel leaves printer ready to retry
- Uses Mainsail `_CLIENT_VARIABLE`: park at cancel over bucket (120,250), cancel retract 5 -> 1 mm, `user_cancel_macro: _KEEP_HOT`.
- `_KEEP_HOT` re-heats bed to last print temp + nozzle to 150 for 15 min, then `_KEEP_HOT_OFF` turns heaters off.
- `COOLDOWN` (heaters off + cancel timer), `KEEP_HOT ENABLE=0|1 MINUTES=n`.
- Caveat: any error-triggered cancel (virtual_sdcard on_error_gcode) also keeps heat for 15 min.

## exhaust_fan_v2.cfg — exhaust fan under macro control
- Replaces `[heater_fan exhaust_fan]` (100% when bed > 60 C) with `[fan_generic exhaust_fan]` on PD13. Old section must be deleted from fans.cfg.
- ABS/ASA (bed >= 90): off while printing. PLA/PETG: 60%. PRINT_END: 100% for 5 min then off.

## Still open (at the time)
- Safety limits (min_temp / min_extrude_temp) in extruder_bed.cfg.
- controller_fan -> `[controller_fan]`.
- Tune z_hot_offset and Orca first-layer flow (0.926).

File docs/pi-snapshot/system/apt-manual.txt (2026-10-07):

adduser
apt
apt-listchanges
apt-utils
autoconf
avahi-daemon
avr-libc
avrdude
base-files
base-passwd
bash
bash-completion
bc
binutils-arm-none-eabi
binutils-avr
bsdutils
build-essential
ca-certificates
cifs-utils
cmake
console-setup
coreutils
cpio
crda
cron
crudini
curl
dash
debconf
debconf-i18n
debconf-utils
debian-archive-keyring
debianutils
dfu-util
dhcpcd5
diffutils
dmidecode
dmsetup
dosfstools
dphys-swapfile
dpkg
e2fsprogs
ed
ethtool
fake-hwclock
fbset
fdisk
ffmpeg
file
findutils
firmware-atheros
firmware-brcm80211
firmware-libertas
firmware-misc-nonfree
firmware-realtek
fonts-ipafont
fonts-nanum
gcc
gcc-10-base
gcc-9-base
gcc-arm-none-eabi
gcc-avr
gdb
gir1.2-gtk-3.0
git
gpgv
grep
gzip
hardlink
hostname
htop
i2c-tools
ifupdown
imagemagick
init
init-system-helpers
iproute2
iptables
iputils-ping
isc-dhcp-client
isc-dhcp-common
keyboard-configuration
kmod
kms++-utils
less
libacl1
libapparmor1
libapt-pkg6.0
libargon2-1
libatlas-base-dev
libatlas3-base
libattr1
libaudit-common
libaudit1
libavcodec-dev
libavformat-dev
libavutil-dev
libblkid1
libbpf0
libbsd-dev
libbsd0
libbz2-1.0
libc-bin
libc6
libcairo2-dev
libcamera-apps-lite
libcamera-dev
libcap-ng0
libcap2
libcap2-bin
libcom-err2
libcrypt1
libcryptsetup12
libdb5.3
libdbus-glib-1-dev
libdebconfclient0
libdevmapper1.02.1
libdns-export1110
libedit2
libelf1
libestr0
libevent-dev
libext2fs2
libfastjson4
libfdisk1
libffi-dev
libffi7
libfreetype6-dev
libgcc-s1
libgcrypt20
libgirepository1.0-dev
libgmp10
libgnutls30
libgpg-error0
libgssapi-krb5-2
libhogweed6
libidn2-0
libip4tc2
libisc-export1105
libjansson4
libjpeg-dev
libjson-c5
libk5crypto3
libkeyutils1
libkmod2
libkrb5-3
libkrb5support0
liblivemedia-dev
liblmdb-dev
liblocale-gettext-perl
liblognorm5
liblz4-1
liblzma5
libmd0
libmnl0
libmount1
libmpv-dev
libmtp-runtime
libncurses-dev
libncurses6
libncursesw6
libnettle8
libnewlib-arm-none-eabi
libnewt0.52
libnftables1
libnftnl11
libnsl2
libopenjp2-7
libp11-kit0
libpam-chksshpwd
libpam-modules
libpam-modules-bin
libpam-runtime
libpam0g
libpcre2-8-0
libpcre3
libpopt0
libprocps8
libraspberrypi-bin
libraspberrypi-dev
libraspberrypi-doc
libraspberrypi0
libreadline8
librsvg2-common
libseccomp2
libselinux1
libsemanage-common
libsemanage1
libsepol1
libslang2
libsmartcols1
libsodium-dev
libss2
libssl-dev
libssl1.1
libstdc++6
libsystemd0
libtasn1-6
libtext-charwidth-perl
libtext-iconv-perl
libtext-wrapi18n-perl
libtinfo6
libtirpc-common
libtirpc3
libudev1
libunistring2
libusb-1.0-0-dev
libusb-dev
libuuid1
libxtables12
libxxhash0
libzstd1
locales
login
logrotate
logsave
lsb-base
lua5.1
luajit
man-db
manpages-dev
mawk
mkvtoolnix
mount
nano
ncdu
ncurses-base
ncurses-bin
net-tools
netbase
network-manager
nfs-common
nftables
nginx
ntfs-3g
openssl
p7zip-full
packagekit
parted
passwd
pciutils
perl-base
pi-bluetooth
pkg-config
policykit-1
procps
psmisc
python-is-python3
python3
python3-dev
python3-distutils
python3-gpiozero
python3-libgpiod
python3-matplotlib
python3-picamera2
python3-pip
python3-rpi.gpio
python3-serial
python3-setuptools
python3-virtualenv
raspberrypi-archive-keyring
raspberrypi-bootloader
raspberrypi-kernel
raspberrypi-net-mods
raspberrypi-sys-mods
raspi-config
raspinfo
readline-common
rng-tools
rpi-eeprom
rpi-update
rsync
rsyslog
sed
sensible-utils
ssh
ssh-import-id
stm32flash
strace
sudo
systemd
systemd-sysv
systemd-timesyncd
sysvinit-utils
tar
tasksel
tasksel-data
tzdata
udev
udisks2
unzip
usb-modeswitch
usbutils
userconf-pi
util-linux
v4l-utils
vim
vim-common
vim-tiny
virtualenv
whiptail
wireless-tools
wpasupplicant
x11-xserver-utils
xinit
xinput
xserver-xorg-input-evdev
xserver-xorg-input-libinput
xserver-xorg-legacy
xserver-xorg-video-fbdev
xxd
zip
zlib1g
zlib1g-dev

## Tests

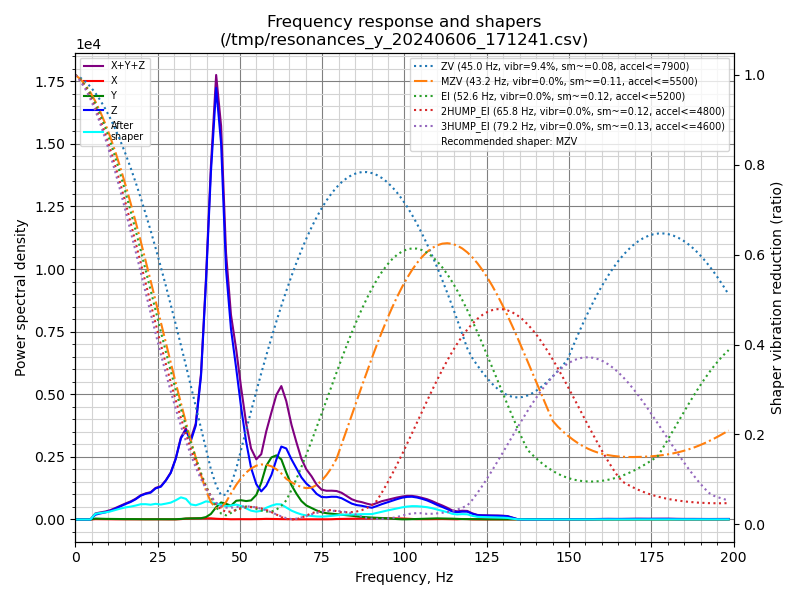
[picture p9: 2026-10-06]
docs/calibration/shaper_calibrate_y.png

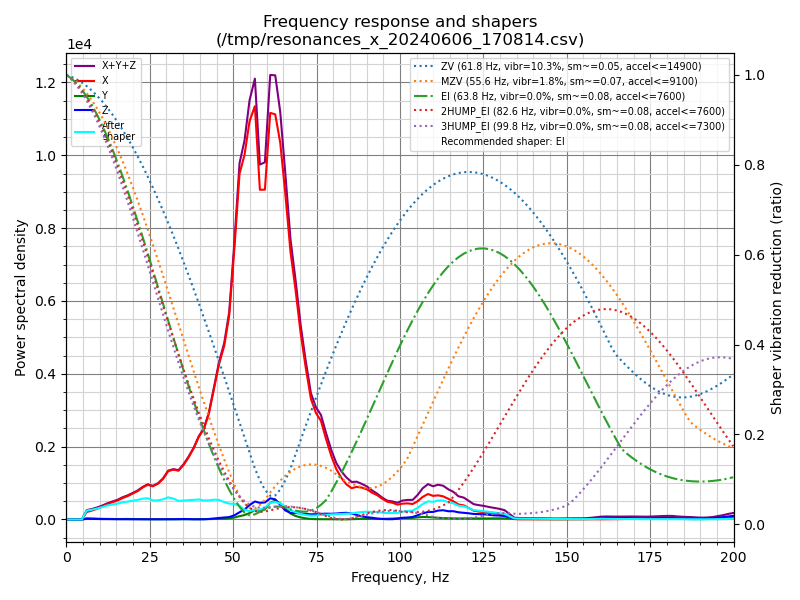
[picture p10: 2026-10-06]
docs/calibration/shaper_calibrate_x.png

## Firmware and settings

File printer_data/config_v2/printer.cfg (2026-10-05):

######################################################################
##  VORON 2.4  (250 mm)  --  printer.cfg   (config_v2, 2026-10-03)
##
##  HOW KLIPPER READS THIS
##  ----------------------
##  * Klipper reads printer.cfg at startup (or on FIRMWARE_RESTART /
##    RESTART). Each [section] configures one "object" (a stepper, a
##    heater, a macro ...).
##  * [include x.cfg] pastes another file in at that point. Splitting the
##    config into files changes nothing for Klipper - it's just for us.
##  * If the same [section] appears twice, the later one's options win.
##    If a PIN is used twice, Klipper refuses to start (good safety net).
##  * Lines starting with # are comments. So is anything after " #" or
##    " ;" on a line.
##  * The block at the very bottom that starts with "#*#" is written by
##    Klipper itself when you run SAVE_CONFIG (PID values, Beacon model,
##    saved meshes). Never edit it by hand - and don't define the same
##    option above, or SAVE_CONFIG will complain.
##
##  BASELINE
##  --------
##  Layout follows the official Voron 2.4 / BTT Octopus reference config
##  (github.com/VoronDesign/Voron-2 -> firmware/klipper_configurations)
##  plus Beacon's official docs (docs.beacon3d.com). Every machine-
##  specific number (pins, currents, offsets, PID, input shaper,
##  rotation_distance, Beacon serial) was carried over from your
##  previous config. See README.md for the full list of changes.
######################################################################


######################################################################
##  INCLUDES
######################################################################

## Mainsail's standard macros: PAUSE / RESUME / CANCEL_PRINT, plus
## [virtual_sdcard], [pause_resume], [display_status].
## Included straight from the mainsail-config repo so updates through
## Mainsail's Update Manager apply automatically (your old setup used a
## stale copy). If your Pi user isn't "pi", fix the path.
[include /home/pi/mainsail-config/mainsail.cfg]

## --- Hardware: one file per physical subsystem ---
[include hardware/motors.cfg]          ## X/Y/Z steppers + TMC2209 drivers
[include hardware/extruder.cfg]        ## Clockwork 2 extruder + hotend heater
[include hardware/bed.cfg]             ## Bed heater (SSR) + thermistor
[include hardware/beacon.cfg]          ## Beacon probe, QGL, bed mesh, resonance tester
[include hardware/fans.cfg]            ## Part, hotend, controller, exhaust, Nevermore
[include hardware/leds.cfg]            ## Case lights + Stealthburner LEDs (+ hidden _STATUS_ macros)
[include hardware/sensors.cfg]         ## MCU / Pi temperatures (+ chamber template)

## --- Macros: what the printer *does* ---
## MACRO NAMING CONVENTION (keeps Mainsail's Macros panel tidy)
##   UPPER_CASE   = a command you run by hand -> shows as a button
##   _anything    = internal helper / console tool -> hidden in Mainsail
##   Prefixes group related buttons when sorted:
##     CAL_*      calibration            LIGHTS_*   lighting
##     NOZZLE_*   clean / prime / purge   PARK_*     toolhead parking
##   Kept as-is on purpose (standards other tools look for):
##     PRINT_START, PRINT_END (Orca start/end G-code), G32 (Voron),
##     M600, LOAD_FILAMENT / UNLOAD_FILAMENT (Mainsail & KlipperScreen
##     load/unload buttons), PAUSE / RESUME / CANCEL_PRINT (Mainsail)
##   Every visible macro has a description: (tooltip in Mainsail).
[include macros/print_start_end.cfg]   ## PRINT_START / PRINT_END (retry-aware)
[include macros/cancel_keep_hot.cfg]   ## Cancel parks + keeps heat for a fast retry
[include macros/nozzle_clean.cfg]      ## Brush wipe, bucket prime, purge line
[include macros/utility.cfg]           ## G32, PARK, PREHEAT, COOLDOWN, filament load/unload, M600
[include macros/calibration.cfg]       ## PID / input-shaper / PA / Beacon helper macros
[include macros/debug.cfg]             ## VIEW_VARIABLES (+ hidden _DUMP_VARIABLES, _GET_VARIABLE)

## --- Playground. Any *.cfg you drop in experimental/ is loaded. ---
## (Rename to .cfg.disabled to switch one off. Empty is fine.)
[include experimental/*.cfg]


######################################################################
##  MAIN CONTROLLER (BTT Octopus)
######################################################################

[mcu]
## The Octopus talks to the Pi over the Pi's hardware UART (GPIO 14/15),
## not USB. That's what /dev/ttyAMA0 is.
serial: /dev/ttyAMA0
restart_method: command


######################################################################
##  PRINTER KINEMATICS & LIMITS
######################################################################

[printer]
kinematics: corexy
## Hard ceilings. The slicer can ask for less (it sends SET_VELOCITY_LIMIT
## during the print) but never more.
max_velocity: 300            # mm/s
max_accel: 4000              # mm/s^2  (your previous value)
max_z_velocity: 25
max_z_accel: 350
## How fast the toolhead may take a 90-degree corner without slowing to
## zero. 5 is the Klipper default and a good value for a 2.4.
square_corner_velocity: 5.0


[input_shaper]
## Cancels frame/belt ringing ("ghosting"). Values came from your last
## SHAPER_CALIBRATE run. Re-run SHAPER_CALIBRATE after any mechanical
## change (belts, toolhead) - see macros/calibration.cfg.
shaper_type_x: ei
shaper_freq_x: 65.2
shaper_type_y: mzv
shaper_freq_y: 41.8


[idle_timeout]
## After this many seconds of doing nothing, Klipper turns off heaters
## AND motors. Turning motors off loses "homed" and the QGL, so the next
## print does the full routine.
## CHANGED: 7200 (2 h) -> 1800 (30 min). Two hours of a 105C bed with
## nobody around is a lot; 30 min still comfortably covers the 15-minute
## keep-hot-after-cancel window.
timeout: 1800


[respond]
## Lets macros print messages to the console (M118 / RESPOND).
default_type: echo
default_prefix:


[exclude_object]
## Lets you cancel a single failed part from Mainsail mid-print. Orca
## already writes the needed EXCLUDE_OBJECT_DEFINE lines, and the
## adaptive mesh uses the same data to only scan where parts are.


[gcode_arcs]
## NICE-TO-HAVE (new): understands G2/G3 arcs. Only matters if you turn
## on "Arc fitting" in Orca (smaller gcode, smoother curves). Harmless
## otherwise.
resolution: 0.1


[save_variables]
## NICE-TO-HAVE (new): a small file where macros can remember values
## across restarts (e.g. a tuned Z offset per material, or the Beacon
## thermal-expansion tool if you add it later).
filename: ~/printer_data/config/variables.cfg


######################################################################
######################################################################
##  Everything below the SAVE_CONFIG line is managed by Klipper.
######################################################################
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

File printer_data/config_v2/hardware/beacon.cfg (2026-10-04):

######################################################################
##  hardware/beacon.cfg  --  Beacon probe + gantry levelling + bed mesh
##
##  HOW BEACON WORKS (short version)
##  * Beacon is an eddy-current sensor: a coil under the toolhead "feels"
##    the distance to the metal bed without touching it ("proximity").
##    It's fast - it can scan the whole bed while moving.
##  * Proximity readings drift with temperature, so Beacon keeps a
##    "model" that maps coil readings to mm. CALIBRATE builds that model.
##  * "Contact" mode (RevH) instead lowers the NOZZLE until it actually
##    touches the bed, sensed by Beacon's accelerometer. That gives a true
##    nozzle-to-bed zero -> no manual Z offset needed.
##  * Typical flow (Beacon docs): contact-home + calibrate on a hot bed ->
##    QGL (proximity) -> mesh (proximity scan) -> wipe nozzle -> final
##    contact Z home -> heat to print temp -> small offset for nozzle
##    thermal expansion. That's what PRINT_START does.
##
##  Docs: https://docs.beacon3d.com/contact/
######################################################################

[beacon]
## Unique USB id of YOUR Beacon (unchanged from your config).
serial: /dev/serial/by-id/usb-Beacon_Beacon_RevH_671857085154364134202020FF152211-if00

## Where the Beacon coil is relative to the nozzle (mm).
## Stealthburner Beacon mount: directly behind the nozzle -> X 0, Y +25.
x_offset: 0
y_offset: 25

## --- Mesh scanning ---------------------------------------------------
mesh_main_direction: x           # scan in rows along X
mesh_runs: 1                     # 2 = scan twice and average (slower, a bit smoother)

## --- Homing ------------------------------------------------------------
## Beacon replaces [safe_z_home]: it moves to this XY before homing Z.
home_xy_position: 125, 125       # bed centre
home_z_hop: 5                    # lift before moving XY (mm)
home_z_hop_speed: 30
home_xy_move_speed: 300

home_method: contact             # first Z home of a session = nozzle touch
home_method_when_homed: proximity  # later plain G28's use the (fast) coil
home_autocalibrate: unhomed      # first contact home also builds the model

## NEW (explicit): Beacon refuses to contact-home with a nozzle hotter than
## this (hot nozzles ooze and can damage PEI). 180 is the Beacon default;
## PRINT_START contact-homes at 150.
contact_max_hotend_temperature: 180


######################################################################
##  QUAD GANTRY LEVEL (QGL)
##  Measures the 4 corners and drives the 4 Z motors until the gantry is
##  parallel to the bed. Needed after motors have been off (they can
##  drift), so PRINT_START runs it once and skips it on retries.
######################################################################
[quad_gantry_level]
## gantry_corners: approximate XY of the gantry pivot points, OUTSIDE the
## bed. Voron reference values for a 250 mm build.
gantry_corners:
    -60,-10
    310, 320
## points: where the NOZZLE goes to probe (Beacon sits 25 mm behind it,
## so it actually measures at Y+25). Voron reference values for 250 mm.
points:
    50,25
    50,175
    200,175
    200,25
speed: 300                       # CHANGED 400 -> 300 (= max_velocity; 400 was silently clamped)
horizontal_move_z: 2             # Beacon is happy probing from 2 mm
retries: 5
retry_tolerance: 0.0075          # mm. QGL repeats until all corners within this
max_adjust: 10


######################################################################
##  BED MESH
##  A height map of the bed, so Z follows small dips/bumps while printing
##  the first layers. Your bed is very flat (your old 31x31 mesh spans
##  about 0.05 mm total) - the mesh is a refinement, not a crutch.
######################################################################
[bed_mesh]
speed: 300
horizontal_move_z: 2
mesh_min: 25, 25                 # these are NOZZLE coordinates
mesh_max: 225, 225
## CHANGED 9,9 -> 15,15. Beacon *scans* (doesn't stop at each point), so
## more points costs very little time. ADAPTIVE=1 only scans the area
## your parts cover and scales the point count down automatically.
probe_count: 15, 15
algorithm: bicubic
## Mesh correction fades out between these heights; above 10 mm the
## printer trusts the gantry (prints don't need the mesh up high).
fade_start: 0.6
fade_end: 10.0
## Mesh value at this XY is treated as "zero". Matches the spot Beacon
## contact-homes at, so mesh and Z home agree.
zero_reference_position: 125, 125
## Extra margin (mm) around the parts when ADAPTIVE=1.
adaptive_margin: 5
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

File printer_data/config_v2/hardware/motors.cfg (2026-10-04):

######################################################################
##  hardware/motors.cfg  --  A/B (X/Y) and Z steppers + TMC2209 drivers
##
##  QUICK PRIMER
##  * A Voron 2.4 is CoreXY: two motors (A and B) move the toolhead in X
##    and Y together. Klipper still calls them stepper_x / stepper_y.
##  * Four Z motors (one per gantry corner) lift the gantry. QUAD_GANTRY_
##    LEVEL moves them independently to make the gantry flat.
##  * rotation_distance = mm of travel per motor revolution.
##      X/Y: 20-tooth pulley x 2 mm belt pitch = 40.
##      Z  : 40 with gear_ratio 80:16 (the 2.4's Z drive reduction).
##  * microsteps 16 + interpolate: the driver internally smooths to 256.
##  * run_current = amps while moving; hold_current = amps when idle.
##    0.8 A suits the stock LDO 2.0 A motors (Voron reference value).
##  * stealthchop_threshold: 0 = always "SpreadCycle" (strong, a little
##    louder). Recommended for X/Y/Z on a Voron.
##  * sense_resistor 0.110 is correct for the Octopus' TMC2209 modules.
##
##  All pins / currents / positions below are YOUR previous values.
######################################################################


##====================================================================
##  X  -- B motor, Octopus MOTOR0
##====================================================================
[stepper_x]
step_pin: PF13
dir_pin: PF12
enable_pin: !PF14
rotation_distance: 40
microsteps: 16
full_steps_per_rotation: 200     # 400 if you ever fit 0.9-degree motors
endstop_pin: PG6                 # X endstop (switch on the XY joint)
position_min: -2
position_endstop: 248            # X homes to the MAX side (right)
position_max: 249
homing_speed: 100                # don't exceed 100 on a 2.4
homing_retract_dist: 2
homing_positive_dir: true

[tmc2209 stepper_x]
uart_pin: PC4
interpolate: True
run_current: 0.8
hold_current: 0.7                # (Klipper now suggests omitting hold_current; kept as you had it)
sense_resistor: 0.110
stealthchop_threshold: 0


##====================================================================
##  Y  -- A motor, Octopus MOTOR1
##====================================================================
[stepper_y]
step_pin: PG0
dir_pin: PG1
enable_pin: !PF15
rotation_distance: 40
microsteps: 16
full_steps_per_rotation: 200
endstop_pin: PG9                 # Y endstop (switch on the gantry)
position_min: 0
position_endstop: 254            # Y homes to the MAX side (rear)
position_max: 255
homing_speed: 100
homing_retract_dist: 2
homing_positive_dir: true

[tmc2209 stepper_y]
uart_pin: PD11
interpolate: True
run_current: 0.8
hold_current: 0.7
sense_resistor: 0.110
stealthchop_threshold: 0


##====================================================================
##  Z0 -- front left, Octopus MOTOR2
##  Only [stepper_z] gets the endstop/limit settings; Z1-Z3 follow it.
##====================================================================
[stepper_z]
step_pin: PF11
dir_pin: PG3
enable_pin: !PG5
rotation_distance: 40
gear_ratio: 80:16
microsteps: 16
## Beacon acts as the Z endstop ("virtual endstop"). There is no
## physical Z switch, so there's no position_endstop here - Beacon
## supplies it (and Klipper keeps a stale copy in SAVE_CONFIG, harmless).
endstop_pin: probe:z_virtual_endstop
position_min: -2                 # lets babystepping/negative offsets work
position_max: 240
homing_speed: 10
second_homing_speed: 1
homing_retract_dist: 0           # MUST be 0 with Beacon

[tmc2209 stepper_z]
uart_pin: PC6
interpolate: true
run_current: 0.8
hold_current: 0.8                # Z holds at full current so the gantry can't sag
sense_resistor: 0.110
stealthchop_threshold: 0


##====================================================================
##  Z1 -- rear left, Octopus MOTOR3
##====================================================================
[stepper_z1]
step_pin: PG4
dir_pin: !PC1                    # "!" inverts direction (Z1/Z3 are mirrored)
enable_pin: !PA0
rotation_distance: 40
gear_ratio: 80:16
microsteps: 16

[tmc2209 stepper_z1]
uart_pin: PC7
interpolate: true
run_current: 0.8
hold_current: 0.8
sense_resistor: 0.110
stealthchop_threshold: 0


##====================================================================
##  Z2 -- rear right, Octopus MOTOR4
##====================================================================
[stepper_z2]
step_pin: PF9
dir_pin: PF10
enable_pin: !PG2
rotation_distance: 40
gear_ratio: 80:16
microsteps: 16

[tmc2209 stepper_z2]
uart_pin: PF2
interpolate: true
run_current: 0.8
hold_current: 0.8
sense_resistor: 0.110
stealthchop_threshold: 0


##====================================================================
##  Z3 -- front right, Octopus MOTOR5
##====================================================================
[stepper_z3]
step_pin: PC13
dir_pin: !PF0
enable_pin: !PF1
rotation_distance: 40
gear_ratio: 80:16
microsteps: 16

[tmc2209 stepper_z3]
uart_pin: PE4
interpolate: true
run_current: 0.8
hold_current: 0.8
sense_resistor: 0.110
stealthchop_threshold: 0

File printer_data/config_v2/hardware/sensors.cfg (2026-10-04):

######################################################################
##  hardware/sensors.cfg  --  extra temperature readouts
##
##  NICE-TO-HAVE (new). These only DISPLAY temperatures in Mainsail
##  (and log them) - they don't control anything. Handy for spotting an
##  overheating Pi or board, and they cost nothing.
######################################################################

[temperature_sensor octopus]
## The STM32 chip's internal sensor on the Octopus.
sensor_type: temperature_mcu
min_temp: 0
max_temp: 100

[temperature_sensor raspberry_pi]
## The Pi's CPU temperature.
sensor_type: temperature_host
min_temp: 0
max_temp: 100


######################################################################
##  CHAMBER THERMISTOR  (template - not active)
##
##  RECOMMENDED UPGRADE: a ~$2 NTC 100K thermistor hanging mid-chamber,
##  wired to a free Octopus thermistor port (T1 = PF5, T2 = PF6, T3 = PF7).
##  Then PRINT_START can wait for a REAL chamber temperature instead of
##  a fixed number of soak minutes (usually faster, always more
##  consistent). Uncomment, set the pin, FIRMWARE_RESTART, and set
##  variable_chamber_target in macros/print_start_end.cfg.
######################################################################
#[temperature_sensor chamber]
#sensor_type: Generic 3950
#sensor_pin: PF5
#min_temp: 0
#max_temp: 100
#gcode_id: C

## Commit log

2026-10-04 Original Pi config (copied 2026-10-03)
    The config as it was running on the printer, before any changes. Auto-backups, theme images and the Telegram config (contains a bot token) are excluded by .gitignore.
    Claude-Session: https://claude.ai/code/session_01HUGM5gmdv5JozwyDa7iLeQ
    [KlipperScreen.cfg, adxl.cfg, beacon.cfg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]
2026-10-04 Step 2 drafts: retry-aware PRINT_START, keep-hot cancel, exhaust fan
    First drafts, never installed. Superseded by config_v2.
    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
    [cancel_keep_hot.cfg, exhaust_fan_v2.cfg, start_stop_v2.cfg]
2026-10-04 config_v2: clean rebuild of the Klipper config
    Official Voron 2.4 / Octopus layout + Beacon docs. Safety limits restored, exhaust under macro control, retry-aware PRINT_START, keep-hot cancel, fixed purge. Machine-specific values carried over. See printer_data/config_v2/README.md.
    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
    [beacon.cfg, bed.cfg, calibration.cfg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]
2026-10-05 config_v2: macro cleanup (renames, hidden helpers)
    UPPER_CASE = button, _prefix = hidden helper. CAL_/LIGHTS_/NOZZLE_/PARK_ prefixes. Visible macros 45 -> 28. demo motion macros disabled.
    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
    [bed.cfg, calibration.cfg, extruder.cfg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]
2026-10-05 config_v2: VIEW_VARIABLES + KlipperScreen menu
    Read-only VIEW_VARIABLES (tunables / state / NAME / PATH) and a View Variables menu in KlipperScreen. README gains a Related section.
    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
    [printer.cfg]
2026-10-05 Add test prints, working notes and repo README
    test_prints/: calibration prints in run order (Ellis' STLs excluded, no license). docs/notes/: Step 1 review, Step 2 drafts, config_v2 summary. README explains layout and how to view diffs.
    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
    [Klipper_square.stl, Voron_Design_Cube_v7.stl, Warp_Bar_150x20x5.stl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]
2026-10-06 Beacon stays on dev channel; add calibration charts and Pi update walkthrough
    - config_v2/moonraker.conf: keep beacon_klipper on channel "dev". Its last
    tag (v2.0.0) predates current Klipper, so "stable" would break startup.
    - config_v2/README.md: matching note
    - docs/calibration/: input shaper X/Y charts rescued from the Pi's klipper/config
    - docs/: Voron Pi Update Walkthrough PDF
    Claude-Session: https://claude.ai/code/session_01JbcUcU4pKLwi1Nu3niRjwu
2026-10-07 Add v1/v2 config switch scripts and Orca/config diff notes
    - scripts/setup-config-git.sh: one-time, on the Pi. Backs up
    ~/printer_data/config, makes it a git repo with branch v1 (current
    config) and v2 (config_v2 installed), leaves the printer on v1.
    - scripts/switch-config.sh: switch v1 <-> v2. Refuses mid-print,
    auto-commits SAVE_CONFIG changes, restarts Moonraker, sends
    FIRMWARE_RESTART, restarts KlipperScreen, reports Klipper state.
    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
2026-10-07 Notes: correct verify_heater row (Klipper enables it by default)
    Claude-Session: https://claude.ai/code/session_01BCyUD8eNALVVPbJkcww9rY
2026-10-07 scripts: don't abort under set -e when Moonraker/Klipper probes fail
    require_idle and report_klipper use curl|python3 inside $(...); with
    pipefail a failed probe killed the script silently (e.g. while Klipper
    restarts, /printer/info returns 503). Probes now end in '|| true' so the
    unreachable-Moonraker prompt and the wait loop actually run.
2026-10-07 Add read-only Pi backup script (runs from the Mac over ssh)
    Probe is piped over ssh stdin, lint-checked for write commands, reads
    Moonraker only via HTTP GET, and streams a tar to stdout. Output goes to
    gitignored backups/ split into public/ and private/. Supports an ssh
    ControlMaster socket for password-only hosts.
2026-10-07 Add read-only snapshot of the Pi's non-secret system state
    Boot/UART settings, nginx, udev, component SHAs, OS info, enabled
    services. From scripts/backup-pi.sh on 2026-10-07.
    [config.txt]
